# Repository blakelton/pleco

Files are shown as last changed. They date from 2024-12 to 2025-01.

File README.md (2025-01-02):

# Pleco - Hand Vacuum Control System

Pleco is a small handvac that I decided to make for fun!

This repository contains the firmware, configuration details, wiring schimatics, and 3D models for a hand vacuum system based on the **STM32L432KC** MCU. The device is designed to manage a 12V PWM-controlled cooling fan for suction, display operating parameters on an LCD, handle user input for speed control, and monitor battery voltage. Additionally, 3D-printable models for the vacuum enclosure and components are included.

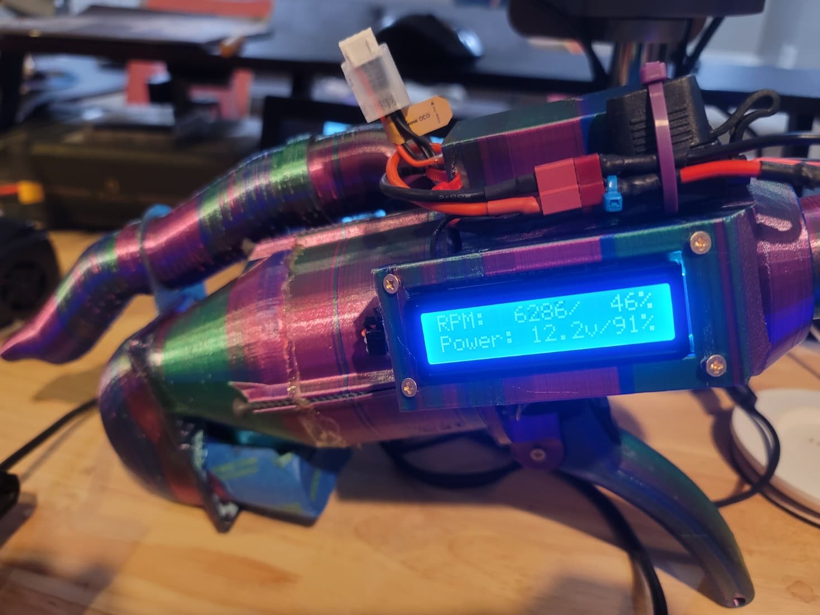
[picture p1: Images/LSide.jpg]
Pleco Left Side


## Overview

The hand vacuum system includes:

- **STM32L432KC Nucleo-32 board** as the main controller.  
- A **12V PWM-controlled cooling fan** for creating vacuum suction.  
- An **I2C LCD 1602 display** for showing fan speed, battery status, and other operational data.  
- A **10kΩ linear potentiometer** for adjusting fan speed.  
- A **3S 11.1V LiPo battery** as the primary power source, with voltage monitoring.  
- **LM2596 DC-DC buck converter** to step down from ~12V battery level to 5V for the MCU and LCD.  
- **Resistors, fuse**, and other components for safe and stable operation.  
- **3D models** available in the `Models` folder for 3D printing the vacuum enclosure and related parts.

## Key Features

1. **Microcontroller (MCU):**  
   - **STM32L432KC (ARM Cortex-M4)** on a Nucleo-32 board.  
   - Provides PWM outputs for fan speed control.  
   - Reads ADC inputs for potentiometer and battery voltage.  
   - Manages I2C communication with the LCD display.  
   - Uses FreeRTOS for task scheduling and concurrency.

2. **Fan Control:**  
   - **12V 40mm PWM-controlled cooling fan**:  
     - PWM signal from MCU adjusts fan speed based on potentiometer input.  
     - Tachometer input to MCU measures fan RPM.  
     - If no pulse is detected for more than 1 second, RPM is set to zero indicating the fan is stopped.

3. **Display:**  
   - **I2C LCD 1602 module**:  
     - Displays fan RPM, battery voltage, and other statuses.  
     - Updated periodically by FreeRTOS tasks.

4. **User Input:**  
   - **10kΩ linear potentiometer** provides an analog voltage representing desired fan speed.

5. **Battery and Power Management:**  
   - **3S 11.1V 1000mAh LiPo Battery** as the main power source.  
   - **Voltage divider (100kΩ & 27kΩ)** and ADC input for battery voltage monitoring.  
   - **2A inline fuse** for overcurrent protection.  
   - **LM2596 buck converter** steps battery voltage down to 5V for the MCU and LCD.

6. **Switches and Connectors:**  
   - **SPST rocker switch** for main power.  
   - **DEAN/JST connectors** for battery connections.  
   - **Assorted wires (18 AWG for power, 22 AWG for signals)** ensure reliable wiring.

7. **3D Models:**  
   - The `Models` folder contains 3D models (STL or other formats) that can be used to 3D print the vacuum enclosure and related mechanical parts. Ensure proper print settings and material selection as per instructions or personal preference.

8. **Wiring Schematics:**  
   - The `Wiring` folder contains a rough wiring schematic for how this system was put together. This folder also includes a pinout for the MCU board. Both of these files are in PDF format.

9. **Software and Firmware:**  
   - **STM32Cube IDE & STM32CubeMX** for HAL configuration and FreeRTOS setup.  
   - **FreeRTOS** for task-based concurrent operations:  
     - Dedicated tasks for fan control, ADC monitoring, LCD updates, and RPM computations.

## Additional Features

- **PID Control:**  
  A robust PID algorithm is implemented for fan speed control, ensuring smooth operation and minimizing overshoot or oscillations.

- **Automated PID Testing:**  
  The firmware includes an optional auto-tuning procedure that tests different Kp, Ki, and Kd values over a defined duration. It computes a performance "score" for each set and picks the best combination for stable fan control.

- **Power Throttling for Low Power:**  
  When the battery voltage drops below a defined threshold, the system automatically reduces the duty cycle to zero, effectively shutting down the fan to prevent deep discharge of the battery.

- **Signal Noise Offset for ADC:**  
  The code applies a configurable noise offset (especially at higher RPM) to combat fluctuations in measured battery voltage, leading to more stable readouts.

## Calculating RPM

If the fan provides, for example, 4 pulses per revolution (PPR):

\[
\text{RPM} = \frac{\text{TimerFrequency} \times 60}{\text{PeriodTicks} \times \text{PulsesPerRev}}
\]

With a 1 MHz timer frequency, you can easily convert measured periods into RPM.

## Disclaimer

**Use this project at your own risk.** The author(s) and contributor(s) assume no liability or responsibility for any damage to property or personal injury that may result from assembling, operating, or modifying this device. Always follow proper safety guidelines, handle batteries carefully, and ensure correct wiring and fuse placement to prevent hazards.

## License

This project is licensed under the [MIT License](LICENSE). You are free to use, modify, and distribute this code under the terms of the MIT License.

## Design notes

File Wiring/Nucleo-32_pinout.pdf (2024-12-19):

STM32 Pin Connected Component | Purpose/Description | Peripheral Mapped To
PA10 /D0 Fan (PWM Output) | Outputs PWM signal to control fan speed. TIM1_CH3
PA3 /A2 | Potentiometer (Wiper) | Reads analog voltage to control fan speed. ADC1_IN8
PB0 /D3 | Voltage Divider | Reads battery voltage for monitoring. | ADC1_IN15
PB6 /D5 | LCD (I2C SCL) | I2C Clock line for LCD. | I2C1_SCL
PB7 /D4 | LCD (I2C SDA) | I2C Data line for LCD. | I2C1_SDA
PA11 /D10 Fan Tachometer (Digital In) Reads fan speed by capturing pulses. | TIM1_CH4

# MCU Board Pinout

Friday, November 29, 2024 10:11 PM

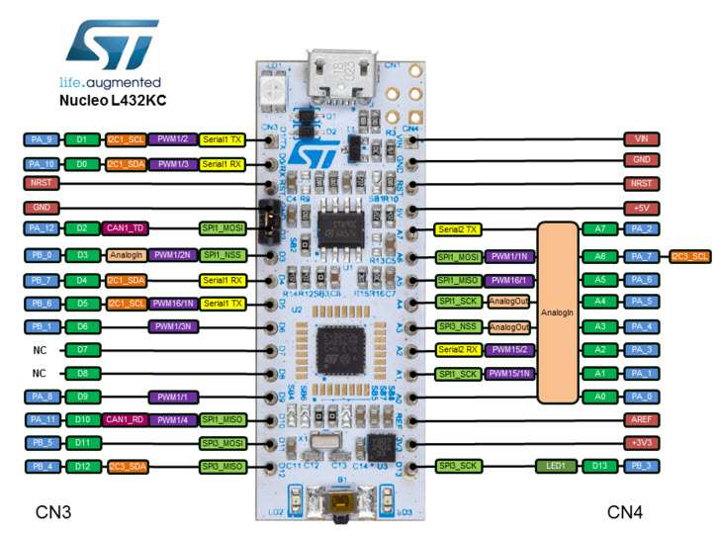
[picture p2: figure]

Pleco Page 1

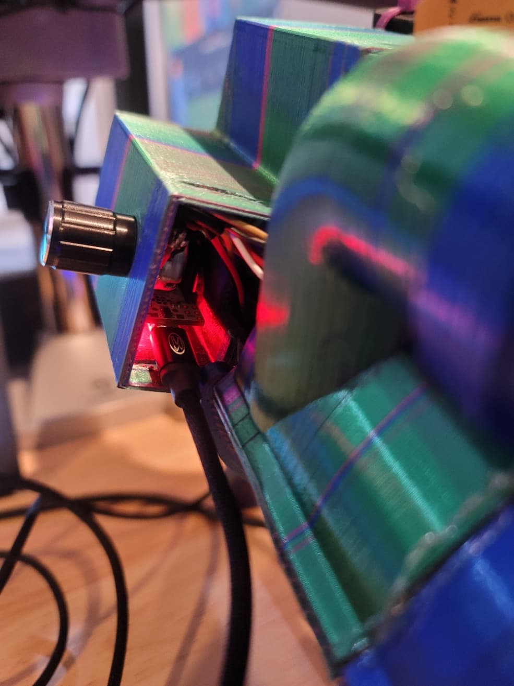
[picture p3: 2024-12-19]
Images/USB_Connector.jpg

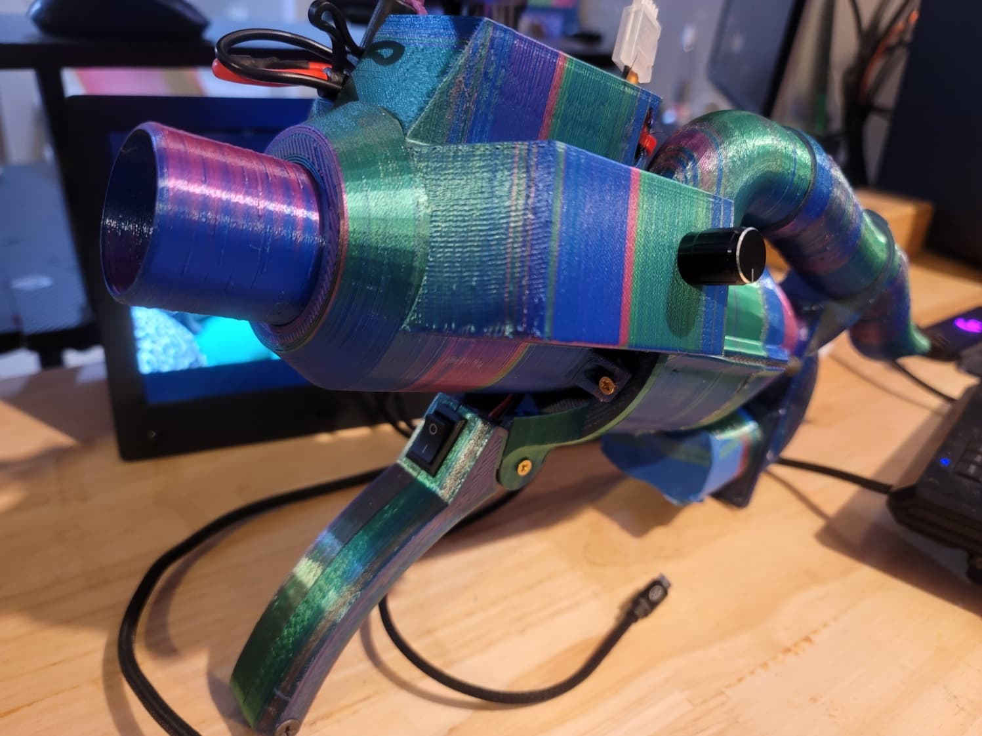
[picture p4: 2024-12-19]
Images/RSide.jpg

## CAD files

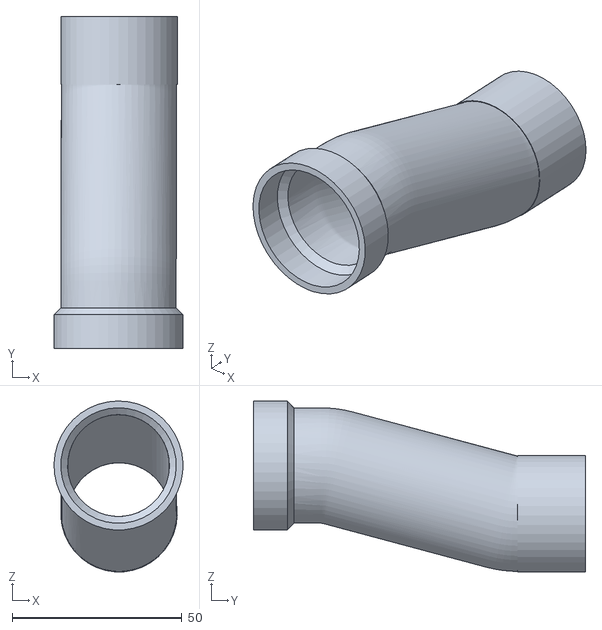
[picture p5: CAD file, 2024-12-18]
Models/intake_upper.STL
38.0 x 97.8 x 50.4

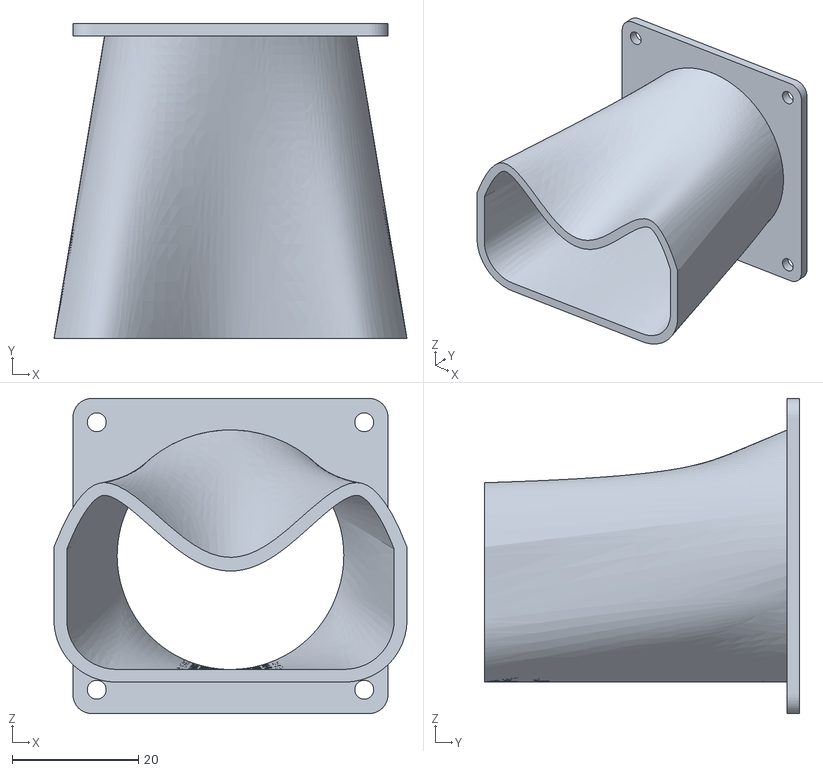
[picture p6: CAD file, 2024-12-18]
Models/catch_drain.STL
56.0 x 50.0 x 50.0

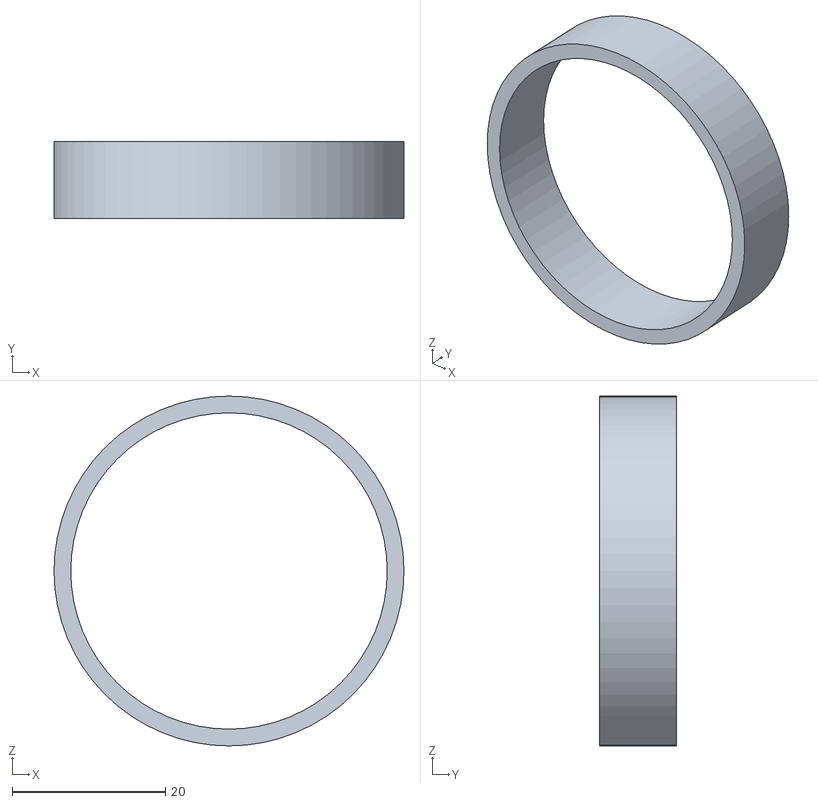
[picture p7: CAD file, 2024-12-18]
Models/filter_ring.stl
45.7 x 10.0 x 45.6

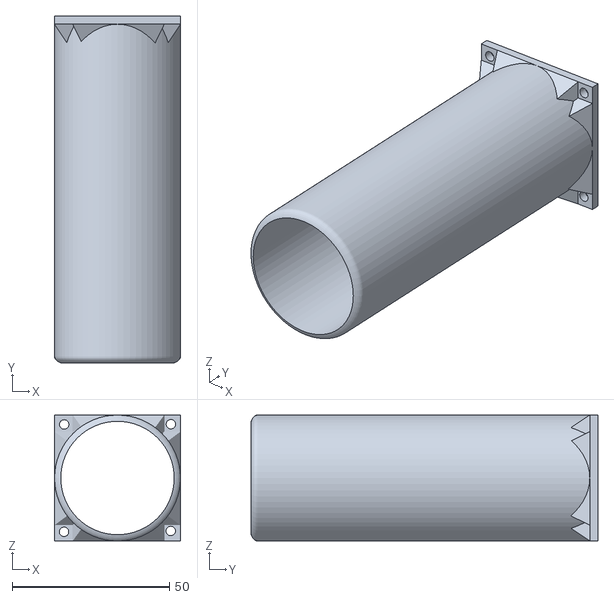
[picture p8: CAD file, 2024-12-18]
Models/exhaust_vent.stl
40.0 x 110.2 x 40.0

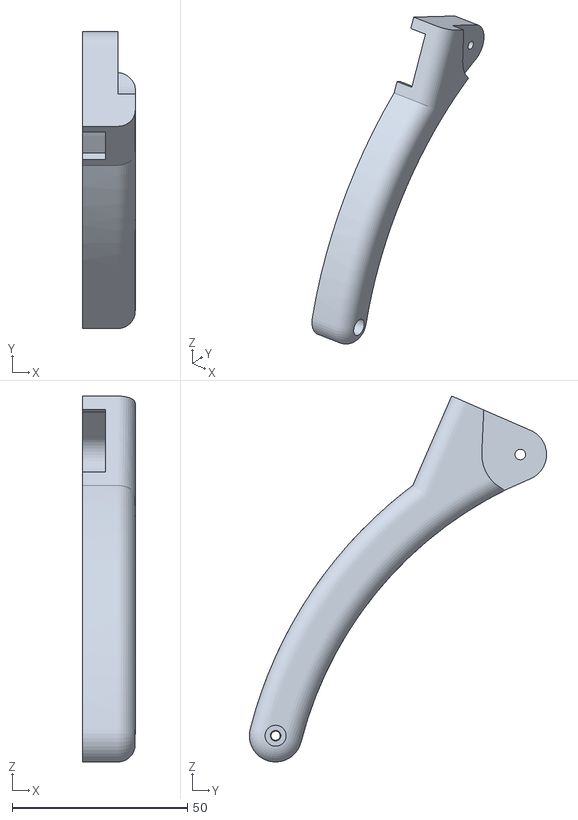
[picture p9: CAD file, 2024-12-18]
Models/handle_left.STL
15.0 x 84.8 x 104.5

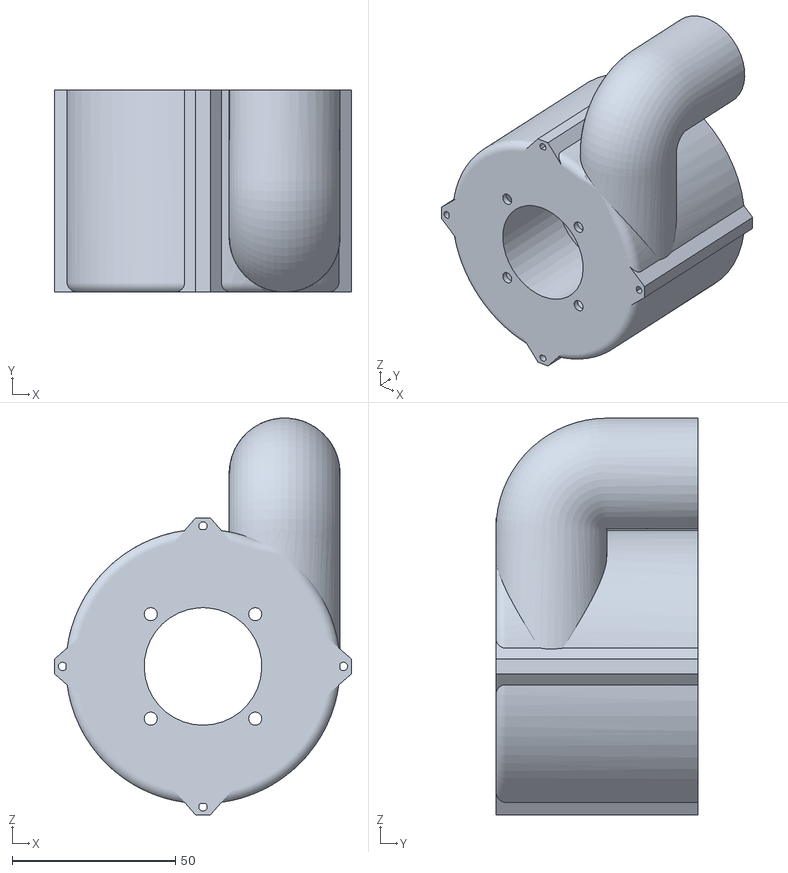
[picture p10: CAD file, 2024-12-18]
Models/cyclone_upper.STL
91.0 x 62.0 x 121.6

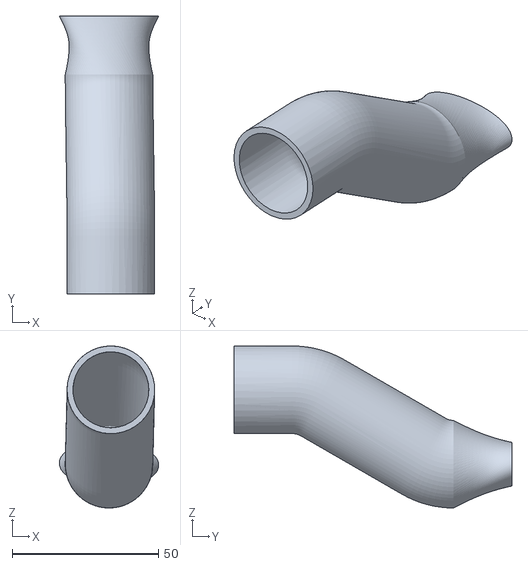
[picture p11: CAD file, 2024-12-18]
Models/intake_lower.STL
34.0 x 95.0 x 55.4

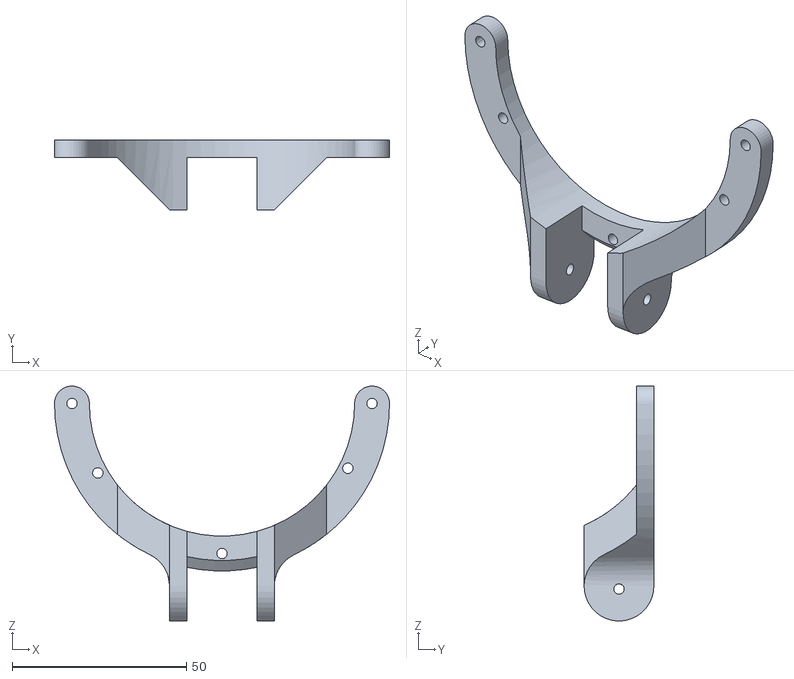
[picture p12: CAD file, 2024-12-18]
Models/handle_adaptor.stl
96.0 x 20.0 x 67.3

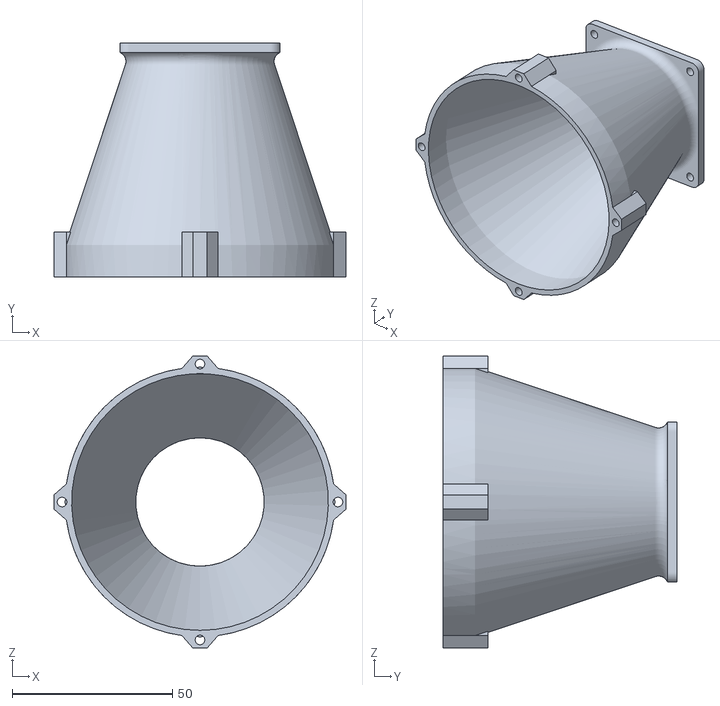
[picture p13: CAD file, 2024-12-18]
Models/cyclone_lower.STL
91.0 x 73.0 x 91.0

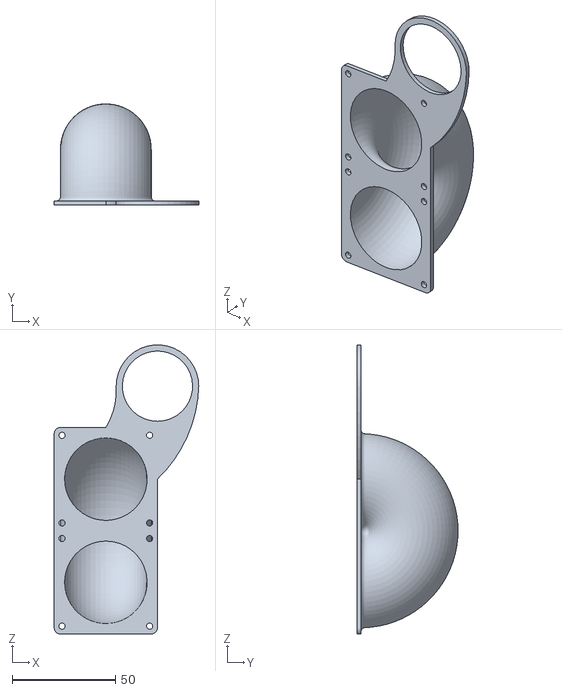
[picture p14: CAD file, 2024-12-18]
Models/cyclone_catch.STL
70.0 x 49.0 x 139.9

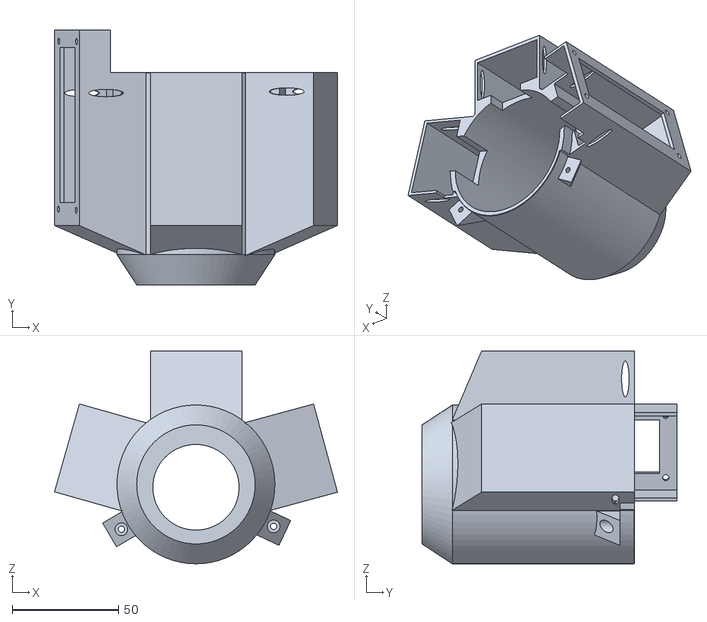
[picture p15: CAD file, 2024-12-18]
Models/electronics_cap.stl
133.2 x 120.0 x 100.1

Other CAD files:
Models/handle_right.STL

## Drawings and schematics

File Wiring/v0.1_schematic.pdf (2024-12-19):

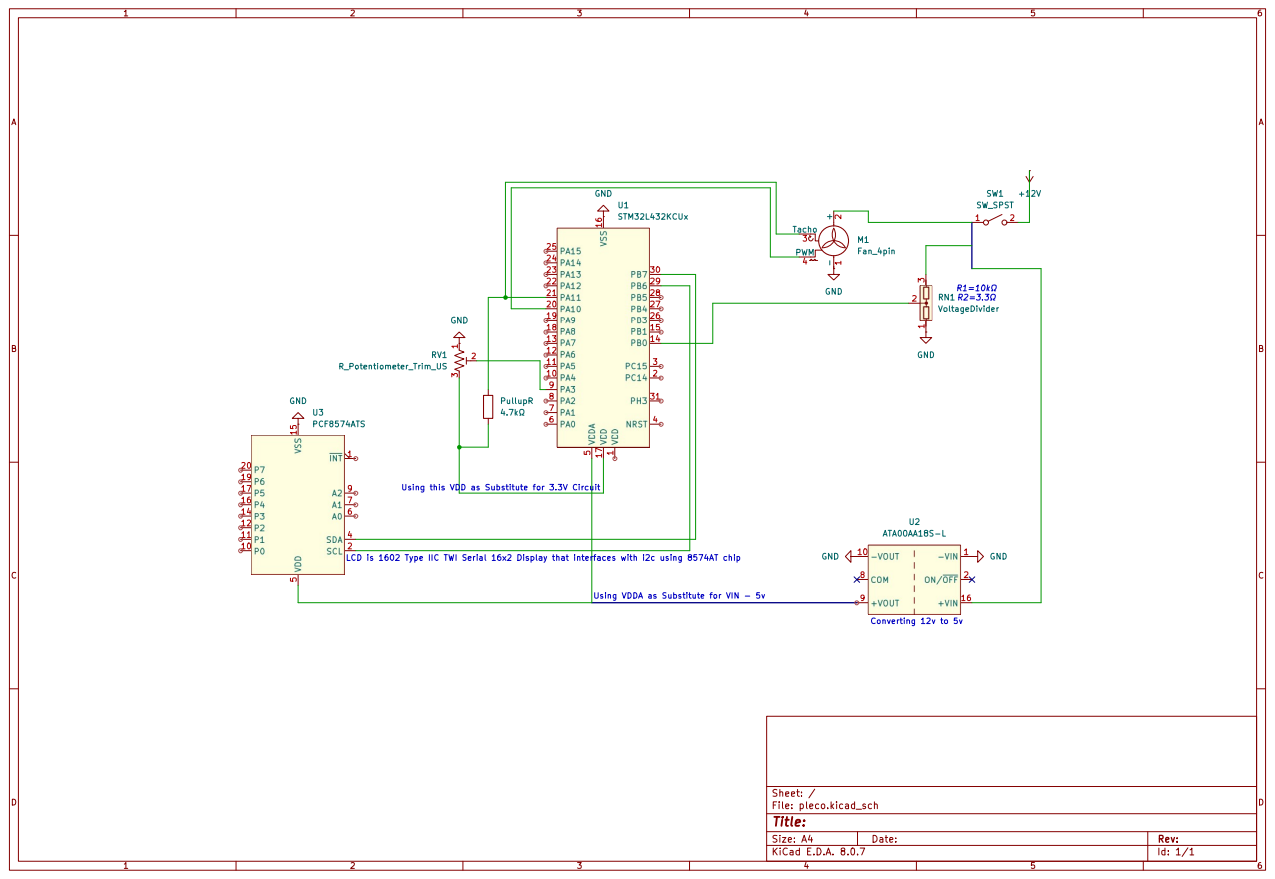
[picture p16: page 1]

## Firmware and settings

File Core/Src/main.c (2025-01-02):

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
/* Includes ------------------------------------------------------------------*/
#include "main.h"
#include "cmsis_os.h"
#include "adc.h"
#include "dma.h"
#include "i2c.h"
#include "tim.h"
#include "usart.h"
#include "gpio.h"

/* USER CODE BEGIN Includes */
void InitializeBatteryMonitoringLog(void);
/* USER CODE END Includes */


/* USER CODE BEGIN PV */
volatile uint32_t overflowCount = 0;

/* USER CODE END PV */

void SystemClock_Config(void);
void MX_FREERTOS_Init(void);
/**
  * @brief  The application entry point.
  * @retval int
  */
int main(void)
{

  /* MCU Configuration--------------------------------------------------------*/

  /* Reset of all peripherals, Initializes the Flash interface and the Systick. */
  HAL_Init();

  /* Configure the system clock */
  SystemClock_Config();

  /* USER CODE BEGIN SysInit */
  InitializeBatteryMonitoringLog();

  /* USER CODE END SysInit */

  /* Initialize all configured peripherals */
  MX_GPIO_Init();
  MX_DMA_Init();
  MX_USART2_UART_Init();
  MX_ADC1_Init();
  MX_I2C1_Init();
  MX_TIM1_Init();
  /* USER CODE BEGIN 2 */

  // Start the PWM output on for fan control
  HAL_TIM_PWM_Start(&htim1, TIM_CHANNEL_3);
  // Initialize Timer 1 for tachometer Feedback
  HAL_TIM_IC_Start_IT(&htim1, TIM_CHANNEL_4);

  /* USER CODE END 2 */

  /* Init scheduler */
  osKernelInitialize();

  /* Call init function for freertos objects (in cmsis_os2.c) */
  MX_FREERTOS_Init();

  /* Start scheduler */
  osKernelStart();

  /* We should never get here as control is now taken by the scheduler */

  /* Infinite loop */
  /* USER CODE BEGIN WHILE */
  while (1)
  {
    /* USER CODE END WHILE */

    /* USER CODE BEGIN 3 */
  }
  /* USER CODE END 3 */
}

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
/**
  * @brief  Period elapsed callback in non blocking mode
  * @note   This function is called  when TIM2 interrupt took place, inside
  * HAL_TIM_IRQHandler(). It makes a direct call to HAL_IncTick() to increment
  * a global variable "uwTick" used as application time base.
  * @param  htim : TIM handle
  * @retval None
  */
void HAL_TIM_PeriodElapsedCallback(TIM_HandleTypeDef *htim)
{
  /* USER CODE BEGIN Callback 0 */
  if (htim->Instance == TIM1)
  {
	// Increment overflow counter
  	overflowCount++;
  }

  /* USER CODE END Callback 0 */
  if (htim->Instance == TIM2) {
    HAL_IncTick();
  }
}

/**
  * @brief  This function is executed in case of error occurrence.
  * @retval None
  */
void Error_Handler(void)
{
  /* USER CODE BEGIN Error_Handler_Debug */
  /* User can add his own implementation to report the HAL error return state */
  __disable_irq();
  while (1)
  {
  }
  /* USER CODE END Error_Handler_Debug */
}

#ifdef  USE_FULL_ASSERT
/**
  * @brief  Reports the name of the source file and the source line number
  *         where the assert_param error has occurred.
  * @param  file: pointer to the source file name
  * @param  line: assert_param error line source number
  * @retval None
  */
void assert_failed(uint8_t *file, uint32_t line)
{
  /* USER CODE BEGIN 6 */
  /* User can add his own implementation to report the file name and line number,
     ex: printf("Wrong parameters value: file %s on line %d\r\n", file, line) */
  /* USER CODE END 6 */
}
#endif /* USE_FULL_ASSERT */

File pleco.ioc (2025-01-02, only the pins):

Mcu.UserName=STM32L432KCUx
PA0.GPIO_Label=MCO [High speed clock in]
PA0.Signal=RCC_CK_IN
PA10.GPIO_Label=PWM Fan Control
PA10.Signal=S_TIM1_CH3
PA11.GPIO_Label=PWM Tach Monitor
PA11.Signal=S_TIM1_CH4
PA2.GPIO_Label=VCP_TX
PA2.Signal=USART2_TX
PA3.GPIO_Label=Pot Monitor
PA3.Signal=ADCx_IN8
PB0.GPIO_Label=Battery Monitor
PB0.Signal=ADCx_IN15
PB6.GPIO_Label=LCD I2C Clock
PB6.Signal=I2C1_SCL
PB7.GPIO_Label=LCD I2C Data
PB7.Signal=I2C1_SDA

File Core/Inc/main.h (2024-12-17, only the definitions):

#define MCO_Pin GPIO_PIN_0
#define MCO_GPIO_Port GPIOA
#define VCP_TX_Pin GPIO_PIN_2
#define VCP_TX_GPIO_Port GPIOA
#define Pot_Monitor_Pin GPIO_PIN_3
#define Pot_Monitor_GPIO_Port GPIOA
#define Battery_Monitor_Pin GPIO_PIN_0
#define Battery_Monitor_GPIO_Port GPIOB
#define PWM_Fan_Control_Pin GPIO_PIN_10
#define PWM_Fan_Control_GPIO_Port GPIOA
#define PWM_Tach_Monitor_Pin GPIO_PIN_11
#define PWM_Tach_Monitor_GPIO_Port GPIOA
#define SWDIO_Pin GPIO_PIN_13
#define SWDIO_GPIO_Port GPIOA
#define SWCLK_Pin GPIO_PIN_14
#define SWCLK_GPIO_Port GPIOA
#define VCP_RX_Pin GPIO_PIN_15
#define VCP_RX_GPIO_Port GPIOA
#define LD3_Pin GPIO_PIN_3
#define LD3_GPIO_Port GPIOB
#define LCD_I2C_Clock_Pin GPIO_PIN_6
#define LCD_I2C_Clock_GPIO_Port GPIOB
#define LCD_I2C_Data_Pin GPIO_PIN_7
#define LCD_I2C_Data_GPIO_Port GPIOB

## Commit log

2024-12-12 Complete Overhaul of Base Code
    - ADC Channels utilizing DMA for value reading
    - Added pot monitoring for 0-100% feedback
    - Fan control added; directly linked to potentiometer feedback
    - Battery Monitoring added - Supports 12.6 3Cell Lipo
    - Display feedback added for Battery Monitoring
    - Tachometer connected (still not reporting)
    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
2024-12-17 Added support for Tachometer Feedback Support for Open Drain style fan
2024-12-18 Added Model files for 3D Printing the Hand Vacuum Added Readme.md to introduce project.
    [catch_drain.STL, cyclone_catch.STL, cyclone_lower.STL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]
2024-12-19 Added images, rough wiring schematic and pinout
2024-12-19 Added image to readme.md and references to the wiring schematic and pinout document.
2024-12-20 Fan was replaced with DBTB0428B2G; - Updated to use falling edge for interupt - Fan also using 2 pulse per revolution for tachometer calculation
    [pleco.ioc, tim.c]
2024-12-20 Added input filter to tachometer feedback to get rid of misleading interupts Modified battery_scaling_factor - TODO: battery scaling is logrithmic and will require a peicewise scaling solution Added 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
2024-12-24 Increase the memory allocation for the FanControlTask Added PID Tuning approach - Problem in PID; need to correct appoach to account for overshoot - current approach causes agressive RPM drops. Added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
    [pleco.ioc]
2024-12-28 PID Tuning and Tuning Function Completed - Set PID Values
2024-12-30 Added hybrid smoothing approach for potentiometer and battery readings - Added hysteresis with low-pass filtering for potentiometer feedback to reduce noise while maintaining responsiveness. - Introd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
2025-01-02 - Removed Battery Scaling Factor for tracking and substituted peicewise linear interpolation - Added empirically derived battery sampling for better power tracking - Added power throttling when power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
2025-01-02 - Added offset to compensate for observed noise in the system
    [main.c]

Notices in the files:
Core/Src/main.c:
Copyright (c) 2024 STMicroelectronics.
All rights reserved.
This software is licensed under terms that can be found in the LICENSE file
